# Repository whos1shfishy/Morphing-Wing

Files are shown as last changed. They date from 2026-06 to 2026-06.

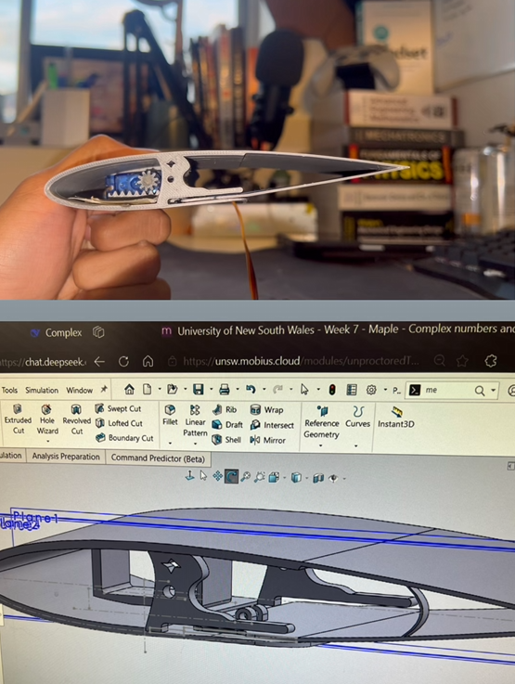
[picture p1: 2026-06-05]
initial wing design.png

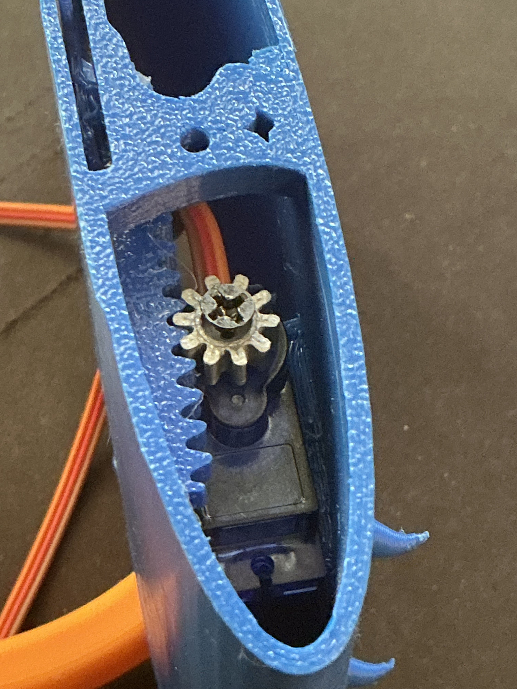
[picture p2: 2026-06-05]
IMG_0116.jpg

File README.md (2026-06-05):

# Flying Fish Morphing Wing

A compact morphing wing concept featuring a **sliding trailing-edge mechanism** driven by a custom dual rack-and-pinion system. This repository documents the sliding-mechanism wing from the UNSW DESN1000 morphing wing project, focusing on the design, CAD structure, assembly, and visual documentation for the `Flying Fish` concept.

## Project overview

The Flying Fish is a 3D-printed morphing wing based on a NACA 0015 airfoil profile with a 150 mm chord and 90 mm span. The design uses a sliding, morphing trailing edge to vary wing camber, with bilateral actuation intended to keep the trailing-edge motion symmetrical and reduce twist.

The project evolved from an earlier single-servo prototype that proved the rack-and-pinion concept worked but highlighted issues such as uneven trailing-edge deflection, twisting under load, and high torque demand on a single actuator. The final Flying Fish design addresses these issues with a dual-servo layout and mirrored mechanisms.

## Key features

- Dual-servo actuation using two SG90 servos, one on each side of the wing
- Custom rack-and-pinion transmission converting servo rotation into linear trailing-edge motion
- Sliding trailing-edge section integrated into the wing structure
- Vertical shaft near the trailing edge to reduce oscillation and maintain primarily horizontal motion
- Lightweight, fully 3D-printed construction for fast iteration and low material usage
- Three-piece assembly (central spine plus two side shells) designed for simple assembly and maintenance

## Design concept

The core idea behind the Flying Fish is to create a morphing trailing edge that can continuously adjust camber without relying on discrete hinged control surfaces. By embedding a rack-and-pinion mechanism inside the wing, servo rotation can be converted into controlled linear motion, pulling or pushing the trailing-edge section.

The initial single-servo concept demonstrated that PLA parts could support morphing, but concentrated load into a single actuator. This produced:
- Asymmetric trailing-edge movement
- Twisting of the morphing section
- Higher torque demand and a greater risk of servo stalling

The dual-servo configuration distributes the load across both sides of the wing and pulls the trailing edge more evenly, improving symmetry and reducing torsional effects.

## Mechanism summary

Each SG90 servo drives a small pinion gear that meshes with a straight rack mounted along the internal trailing-edge structure. As the servo rotates, the pinion drives the rack linearly, which in turn slides the morphing rear section to change camber.

Because the mechanism is mirrored on both sides:
- Both racks move in a coordinated manner
- The trailing edge can be pulled symmetrically
- Twisting and binding are reduced compared with a single central actuator

A vertical shaft near the trailing edge ties the moving section to the upper skin and helps keep the motion primarily horizontal, reducing oscillations during actuation.

## Airfoil and structure

- Airfoil: NACA 0015
- Chord length: 150 mm
- Span: 90 mm
- Materials: PLA for early prototypes, PETG for later versions to increase flexibility and morphing capability
- Structural layout: central internal spine plus two side shells forming the full airfoil profile

The NACA 0015 profile was selected because:
- Its 15 % thickness provided sufficient internal volume for servos, racks, and structural elements
- It offered a good balance between aerodynamic behavior and practical manufacturability with FDM 3D printers

## Repository structure

```text
.
├── README.md
├── cad/
│   ├── assemblies/
│   ├── parts/
│   ├── exports/
│   └── screenshots/
├── images/
│   ├── prototype/
│   ├── final-wing/
│   ├── mechanism/
│   └── presentation/
└── docs/
    ├── project-summary.md
    ├── mechanism-notes.md
    ├── assembly-guide.md
    └── image-checklist.md
```

### `cad/`

Store all CAD assets for the wing.

Suggested subfolders:
- `assemblies/` – full wing assemblies (e.g., complete Flying Fish assembly)
- `parts/` – individual parts such as racks, pinions, side shells, central spine, trailing-edge section, and servo mounts
- `exports/` – neutral/shareable formats such as STEP and STL
- `screenshots/` – CAD renders and orthographic views, including section cuts and annotated views of the mechanism

### `images/`

Store all project images and visual references.

Suggested subfolders:
- `prototype/` – early proof-of-concept builds, single-servo version, cardboard/PLA trials
- `final-wing/` – final assembled Flying Fish in various views
- `mechanism/` – close-ups of racks, pinions, servo mounting, sliding trailing-edge details, and section cuts
- `presentation/` – images from demo/presentation day, wind-tunnel setup, table display, and team photos (if desired)

### `docs/`

Store written documentation that supports the repository.

Recommended files:
- `project-summary.md` – overview of the project, design intent, and evolution
- `mechanism-notes.md` – detailed explanation of the rack-and-pinion architecture and dual-servo design
- `assembly-guide.md` – basic assembly order and important fit/tolerance notes
- `image-checklist.md` – list of recommended photos/diagrams to include

## Hardware and control

This project focuses on the mechanical design rather than custom control firmware. The morphing mechanism can be driven using:
- Two SG90 (or similar) micro servos
- A simple microcontroller (e.g., Arduino) providing PWM signals

For basic demonstrations, both servos can be driven with identical signals so the racks move symmetrically. More advanced control schemes can add:
- Separate channels for each servo
- Potentiometer-based manual control
- Automated morphing profiles

## How to use this repository

1. Clone the repository.
2. Open the CAD assemblies in your preferred CAD package.
3. Export or use the provided STLs from `cad/exports/` for printing.
4. Print and assemble parts following the `docs/assembly-guide.md`.
5. Add your own photos and screenshots into the `images/` folders.
6. Optionally extend the mechanism or control scheme and document changes.

## Short description (for GitHub)

> Compact 3D-printed morphing wing with a dual-servo rack-and-pinion sliding trailing-edge mechanism based on a NACA 0015 airfoil.

## Topics / tags

`morphing-wing` `airfoil` `naca0015` `cad` `aerodynamics` `3d-printing` `servo` `rack-and-pinion` `mechanical-design` `unsw` `desn1000`

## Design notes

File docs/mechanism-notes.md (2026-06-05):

# Mechanism Notes

## Core mechanism

The Flying Fish uses two mirrored rack-and-pinion systems to drive a sliding trailing edge. Each servo is mounted inside the wing and equipped with a small pinion gear fixed to its output shaft. The pinion meshes with a straight rack aligned along the trailing-edge structure.

When the servo rotates:
- The pinion gear turns with it
- The rack translates linearly
- The morphing trailing-edge section is pulled or pushed, changing the airfoil camber

Because this layout is duplicated on both sides of the wing, both racks move in a coordinated fashion, helping the trailing edge morph symmetrically.

## Why dual servos

The initial concept used one central servo driving a single rack-and-pinion. While this validated the mechanical idea, it created several issues:
- The single actuator carried all aerodynamic and structural loads
- The trailing edge deflected unevenly, leading to twisting
- The torque demand on one servo increased, making stalls more likely at higher deflections

Moving to a dual-servo system provides several advantages:
- Load is shared between two actuators
- Each side of the trailing edge is driven independently but symmetrically
- Twisting is reduced, improving the predictability of camber changes
- The system scales better for higher morphing deflections

## Structural guidance

A vertical shaft is positioned near the trailing-edge section to connect the moving morphing part to the upper skin. This shaft:
- Helps maintain alignment of the sliding section
- Guides motion to be primarily horizontal rather than allowing large vertical oscillations
- Works together with the outer shells to preserve the airfoil shape during morphing

The surrounding side shells capture the racks and trailing-edge section, forming a continuous aerodynamic surface while allowing internal components to slide.

## Material considerations

Early builds used PLA due to availability, which provided stiffness but limited flexibility. Later iterations used PETG to increase elasticity and allow greater morphing range while still maintaining structural integrity.

Key trade-offs:
- PLA: stiffer, easier to print, higher risk of fracture in highly flexed regions
- PETG: more flexible, better for morphing sections, requires more tuning of print settings

The combination of PETG trailing-edge components and internal racks allowed the trailing edge to deform under servo actuation while returning close to its original shape when unloaded.

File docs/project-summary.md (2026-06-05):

# Project Summary

The Flying Fish is a sliding-mechanism morphing wing developed as part of a UNSW DESN1000 engineering design project. The goal was to create a wing that can dynamically modify its camber through a morphing trailing edge, improving aerodynamic performance compared with a fixed solid airfoil.

The wing is based on a NACA 0015 profile with a 150 mm chord and 90 mm span. The internal structure houses a custom bilateral rack-and-pinion mechanism driven by two SG90 servos, one on each side of the wing. These servos pull a sliding trailing-edge section to achieve continuous camber change.

Early prototypes used a single central servo and a single rack-and-pinion system, which demonstrated that the concept worked but also revealed asymmetric deflection, twisting under load, and high torque on the lone actuator. The final Flying Fish design transitioned to a dual-servo configuration with mirrored racks on both sides of the trailing edge.

The final implementation uses a three-piece 3D-printed structure (central spine plus two side shells) and, in later versions, PETG material for increased flexibility. This architecture aims to keep the part count and weight low while making assembly, maintenance, and iteration straightforward.

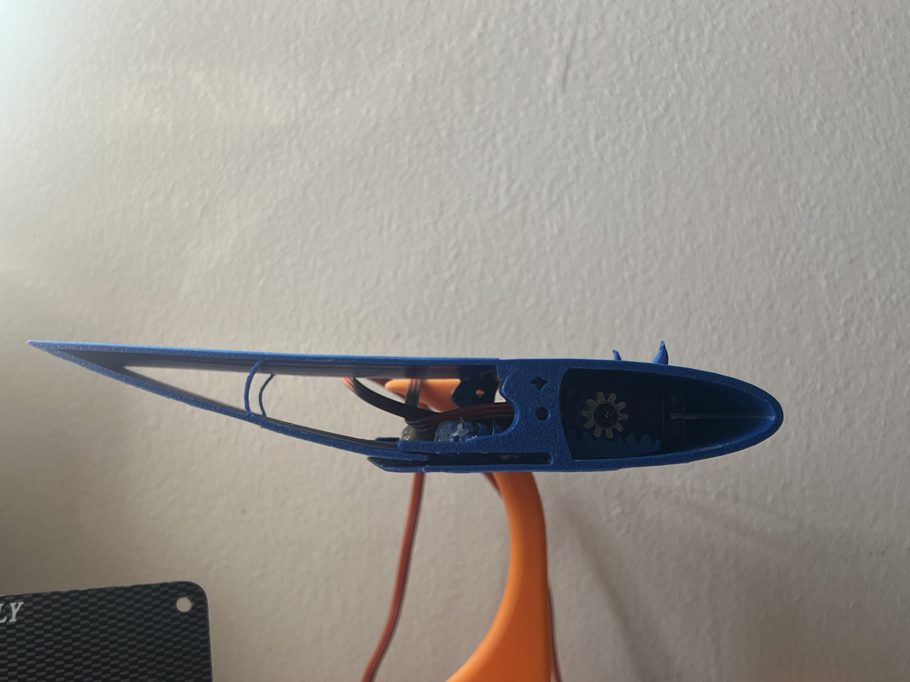
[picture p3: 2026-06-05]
down.jpg

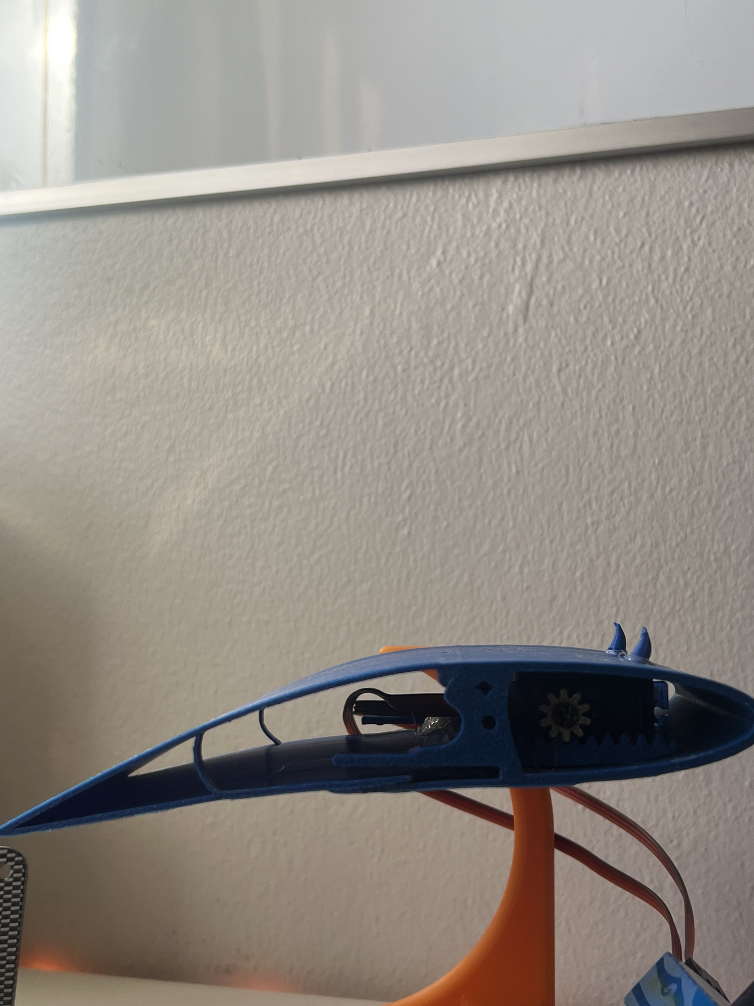
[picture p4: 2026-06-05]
up.jpg

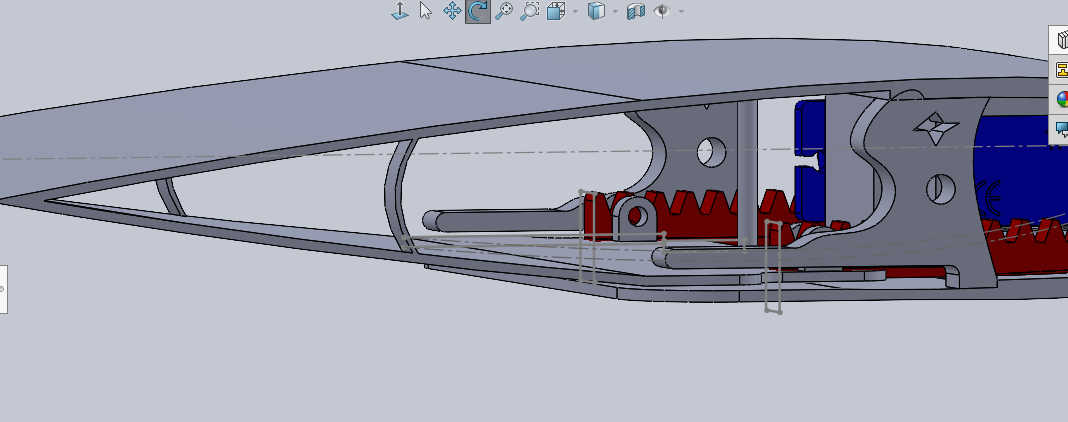
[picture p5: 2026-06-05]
compliant mech.png

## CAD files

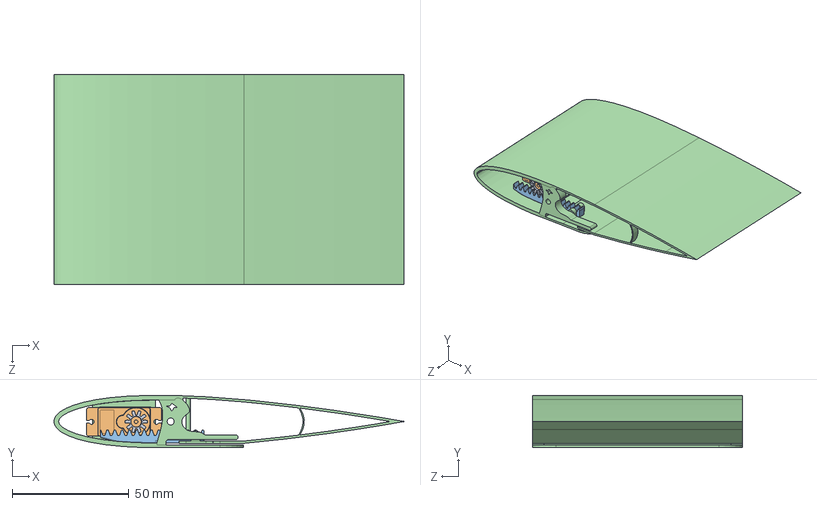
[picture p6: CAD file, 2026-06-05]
Complete wing assembly.SLDASM
150.0 x 22.5 x 90.0 mm
Morphing Wing
rack x 2
SG90 - Micro Servo 9g - Tower Pro.1
gear small

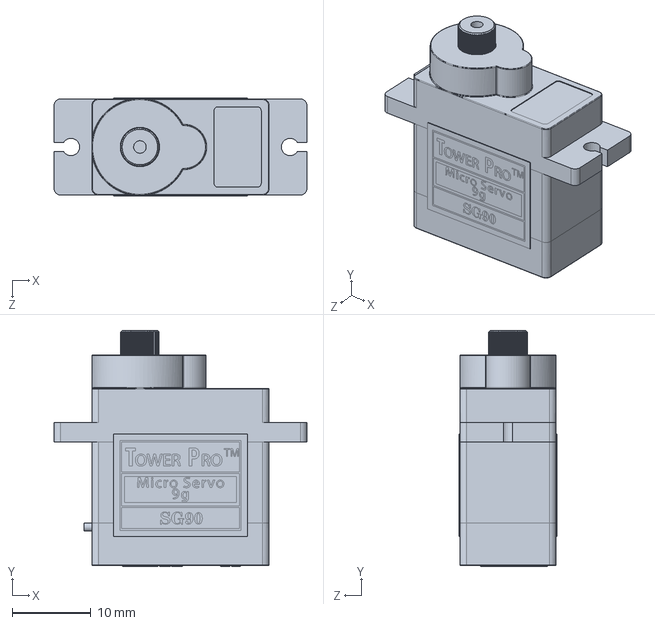
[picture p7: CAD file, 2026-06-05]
SG90 - Micro Servo 9g - Tower Pro.1.SLDPRT
32.1 x 30.0 x 12.4 mm

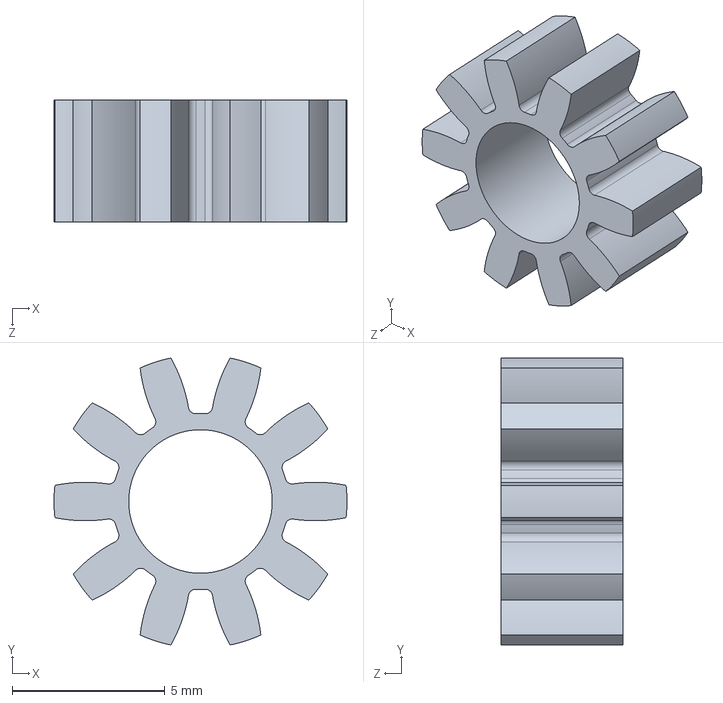
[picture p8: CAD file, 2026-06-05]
gear small.SLDPRT
9.60 x 9.40 x 4.00 mm

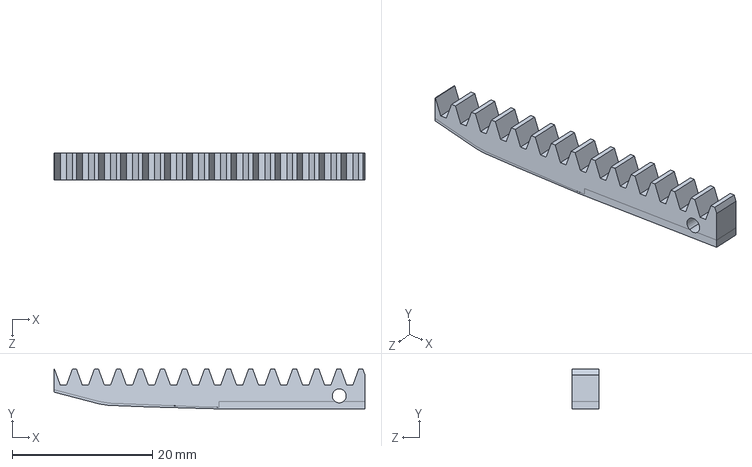
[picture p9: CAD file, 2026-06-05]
rack.SLDPRT
44.3 x 5.64 x 3.90 mm

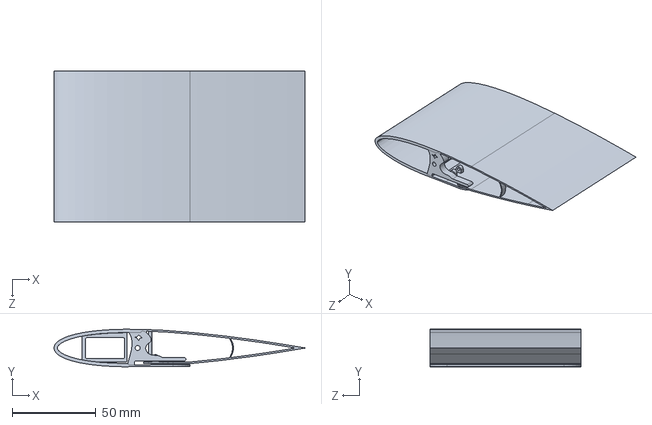
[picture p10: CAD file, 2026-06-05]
Morphing Wing.SLDPRT
150.0 x 22.5 x 90.0 mm

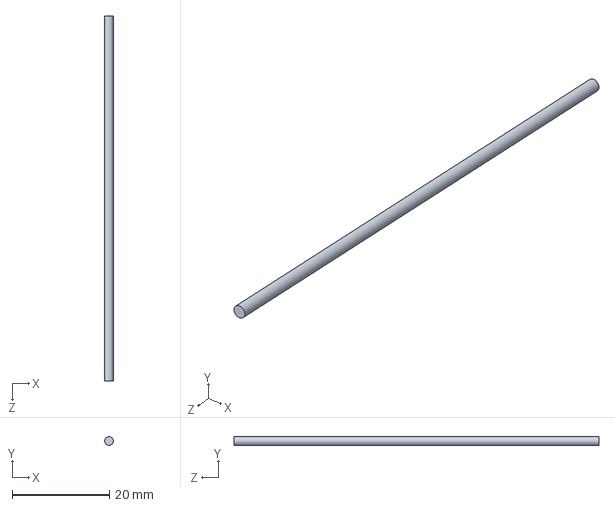
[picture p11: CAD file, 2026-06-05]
shaft.SLDPRT
1.80 x 1.80 x 75.0 mm

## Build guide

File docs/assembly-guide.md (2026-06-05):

# Assembly Guide

This guide describes a suggested assembly order and key setup notes for the Flying Fish morphing wing.

## Parts checklist

Recommended printed parts:
- Central spine / internal frame
- Left and right side shells
- Sliding trailing-edge section
- Two rack components (left and right)
- Two pinion gears sized for the SG90 servo shafts
- Servo mounts and any mounting brackets
- Vertical trailing-edge guide shaft and associated supports

Hardware:
- 2 × SG90 (or similar) micro servos
- Screws or fasteners for securing servos (if needed)
- Any alignment pins or small screws used in the design

## Suggested assembly order

1. **Print all components**  
   Print the central spine, side shells, racks, pinions, trailing-edge section, servo mounts, and any small alignment parts.

2. **Prepare the servos**  
   - Center both SG90 servos (e.g., using a servo tester or microcontroller) so they start from a neutral angle.
   - Press-fit or secure the custom pinion gears onto the servo output shafts.

3. **Install servos into the spine**  
   - Mount both servos into the central spine or internal frame.
   - Ensure they are firmly fixed and aligned so the pinions sit at the correct height relative to the racks.

4. **Install the racks**  
   - Slide the racks into their guides on each side of the trailing-edge structure.
   - Mesh each rack with its corresponding pinion.
   - Verify the teeth engage cleanly without excessive backlash or binding.

5. **Attach the sliding trailing-edge section**  
   - Connect the trailing-edge section to the racks and to the vertical guiding shaft.
   - Ensure the connections allow the trailing edge to move smoothly while staying aligned with the rest of the airfoil.

6. **Check motion before closing the shells**  
   - Gently actuate both servos (by hand or with low-angle commands).
   - Confirm that:
     - Both racks move in the expected direction
     - The trailing edge moves symmetrically
     - There is no significant binding or collisions

7. **Install the side shells**  
   - Fit the left and right side shells over the spine and mechanism.
   - Secure them according to the design (snap-fit, screws, or glue).
   - Make sure the outer surface remains smooth and continuous.

8. **Final motion test**  
   - Run the servos over the intended deflection range.
   - Check that the trailing edge morphs as expected and returns close to neutral when the servos go back to their centered position.

## Setup notes and tips

- **Backlash and clearance**  
  Aim for low backlash in the rack-and-pinion mesh, but avoid over-tight engagement, which can cause binding and excessive friction.

- **Servo synchronization**  
  Start both servos from the same neutral position. If driving them electronically, ensure they receive matched signals for symmetric motion.

- **Print tolerances**  
  Tolerances may need tuning depending on printer, material, and settings. Slight scaling or light sanding of racks and guides may be required for smooth motion.

- **Maintenance**  
  The three-piece structure and modular parts make it easy to swap out a damaged rack, pinion, or trailing-edge section without reprinting the entire wing.

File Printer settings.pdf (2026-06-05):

# Printer settings

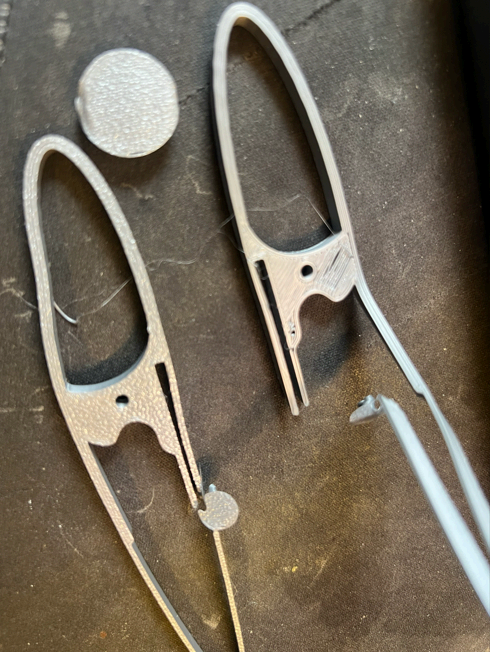
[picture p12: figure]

initial failures

## Quality

- Process profile: 0.16 mm Optimal – BBL A1M.
- Layer height: 0.16 mm.
- Initial layer height: 0.20 mm.wiki.bambulab+1

## Strength

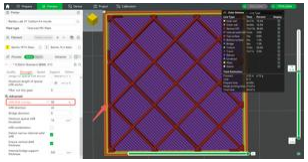
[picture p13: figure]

- Walls (perimeters): 4.
- Top solid layers: 5.
- Bottom solid layers: 4.
- Infill density: 25%.
- Infill pattern: Gyroid.

## Material (PLA)

- Nozzle temperature: 215 °C.
- Bed temperature: 60 °C on smooth plate (55 °C textured).
- Fan: 100% after layer 3.

## Speed

- Mode: Standard.
- Outer wall speed: 60 mm/s.
- Inner wall / infill: leave A1 mini defaults (≈200–250 mm/s).

## Supports

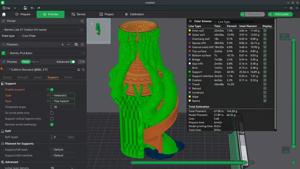
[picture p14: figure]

- Support type: Normal.
- Style: Snug.
- Threshold angle: 50°.
- Support density: 25%.
- Pattern: Grid.
- Interface: On, 2 top interface layers, lines pattern, spacing 0.3 mm.
- Top Z distance: 0.25 mm.
- Bottom Z distance: 0.20 mm.
- Initial support density: 80%.
- Initial support expansion: 3.0 mm.
- Support wall loops: 1.
- Support/object XY distance: 0.25 mm.

## Brim / adhesion

- Brim: Outer brim only.
- Brim width: 8 mm.
- Brim layers: 1.

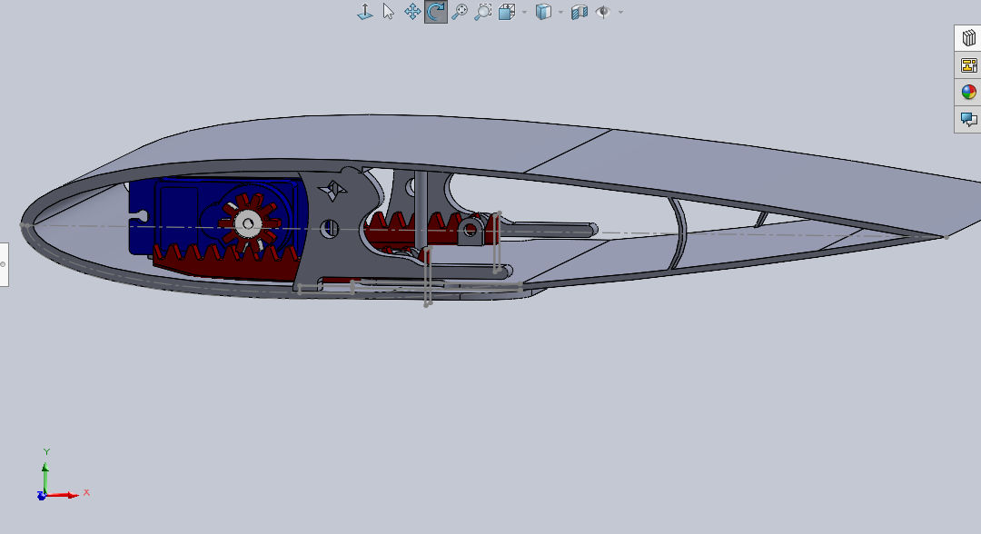
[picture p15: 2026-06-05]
assembly pic.png
